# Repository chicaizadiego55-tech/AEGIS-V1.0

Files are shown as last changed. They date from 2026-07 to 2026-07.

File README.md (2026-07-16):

<p align="center">
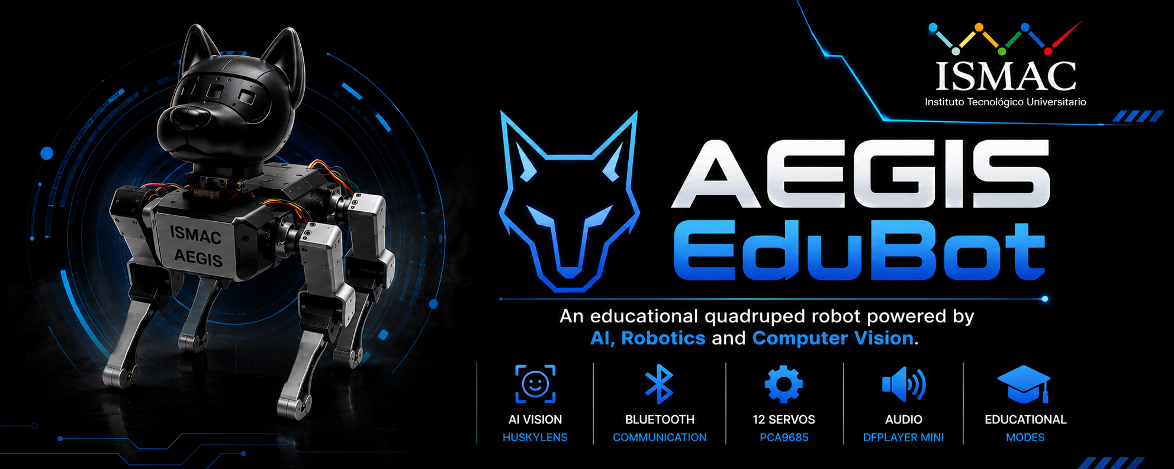
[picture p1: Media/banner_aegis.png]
AEGIS EduBot Banner
  
</p>

<h1 align="center">🐺 AEGIS EduBot</h1>

<p align="center">
An educational quadruped robot powered by ESP32, computer vision, and artificial intelligence.
</p>

<p align="center">






</p>

---

# 📖 Overview

AEGIS (Automated Educational Guide with Intelligent System) is an educational quadruped robot designed to bring artificial intelligence and robotics closer to students through interactive learning experiences.

Its modular architecture combines computer vision, intelligent locomotion, Bluetooth communication and educational activities to promote STEM learning and environmental awareness.

---

# ✨ Features

- 🤖 Quadruped robot
- 👁️ HuskyLens AI Vision
- 📱 Bluetooth communication
- 🎵 DFPlayer Mini audio
- ⚙️ 12 Servo Motors
- 🔋 Battery powered
- 🖨️ Fully 3D Printed
- 🌱 Environmental education

---

# 🎯 Educational Modes

## 👤 Face Recognition

Recognizes previously learned faces and interacts with the user.

---

## 🎨 English Color Learning

Identifies colors while teaching their pronunciation in English.

---

## ♻️ Waste Classification

Recognizes recyclable materials to promote environmental awareness.

---

# 🛠 Hardware

| Component | Model |
|---|---|
| Microcontroller | ESP32 DevKitC V4 |
| Vision | HuskyLens 2 |
| PWM Driver | PCA9685 |
| Audio | DFPlayer Mini |
| Servos | 12x Servo Motors |
| Batteries | Li-Ion 18650 |
| Structure | PLA+ / PETG |

---

# 🚀 Getting Started

Clone the repository

```bash
git clone https://github.com/chicaizadiego55-tech/AEGIS-V1.0.git
```

Open the firmware

```text
Firmware/AEGIS.ino
```

Compile using Arduino IDE with ESP32 Boards installed.

---
# 📄 Documentation

| Folder | Description |
|---|---|
| BOM | Bill of Materials |
| CAD | 3D Models |
| Docs | User & Technical Manuals |
| Electronics | Schematics |
| Firmware | Source Code |
| Results | Validation Data |

---

# 👨‍💻 Developed by

ISMAC – Instituto Tecnológico Universitario

AEGIS EduBot © 2026

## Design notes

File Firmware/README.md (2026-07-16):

# AEGIS EduBot - Firmware 

Este firmware está modularizado para la fácil compilación y control del robot móvil cuadrúpedo AEGIS.

## Requisitos de Librerías
Asegúrate de instalar las siguientes dependencias en tu Arduino IDE o PlatformIO:
1. **Adafruit PWM Servo Driver Library** (para el chip PCA9685)
2. **DFRobot_Huskylens** (para la cámara inteligente)
3. **DFRobotDFPlayerMini** (para el reproductor de sonido)

## Cómo compilar
1. Crea una carpeta llamada `AEGIS` en tu directorio de proyectos de Arduino.
2. Clona o copia el contenido de `AEGIS.ino` dentro de esa carpeta.
3. Crea un subdirectorio llamado `src` al mismo nivel de tu archivo `.ino`.
4. Añade todos los archivos `.h` y `.cpp` dentro de la carpeta `src/`.
5. Abre `AEGIS.ino` en el Arduino IDE y presiona **Upload** (Subir) seleccionando la placa **ESP32 Dev Module**.

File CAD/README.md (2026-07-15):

# Modelos CAD - AEGIS

Esta carpeta contiene los archivos CAD del perro robot **AEGIS**.

## Contenido

-   Diseno_Final.SLDPRT: Modelo CAD principal.
-   SolidWorks: Piezas 

## Software

-   SolidWorks.

## Nota

-   Modelo mecánico del robot.

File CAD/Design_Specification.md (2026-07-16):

# Especificación del diseño mecánico

-   Proyecto: AEGIS
-   Material recomendado: PLA+ o PETG
-   Tecnología: Impresión 3D FDM
-   Componentes integrados: ESP32, HuskyLens 2, PCA9685, DFPlayer Mini y 12 servomotores.

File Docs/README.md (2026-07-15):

# Documentación

Esta carpeta contiene la documentación oficial del proyecto **AEGIS**.

## Contenido

– Guía para la operación del robot.
– Información técnica del hardware y software.
– Presentación general del proyecto.

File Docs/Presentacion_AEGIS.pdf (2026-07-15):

# AEGIS EduBot

### Asistente Robótico Educativo para la Estimulación del Aprendizaje Inicial y la Conciencia Ambiental

Presentación de Defensa de Proyecto de Innovación • 2026

# El Problema

Desafío en Educación Inicial: Los métodos tradicionales de enseñanza para niños de 3 a 5 años sufren de falta de interactividad dinámica, dificultando la retención y la motivación temprana en áreas clave como el bilingüismo y la ecología.

Falta de herramientas tecnológicas interactivas inclusivas adaptadas a la primera infancia.

Dificultad para internalizar hábitos sostenibles (separación de residuos) desde edades tempranas.

Baja exposición práctica a idiomas extranjeros (Inglés) en entornos vulnerables o tradicionales.

•

•

•

AEGIS EduBot — Defensa Final

# Objetivos del Proyecto

Objetivo General

Desarrollar una herramienta tecnológica integral capaz de estimular el aprendizaje en educación inicial mediante visión artificial e interacción humano-robot, convirtiendo la tecnología en una experiencia cercana y dinámica para niños de 3 a 5 años.

Objetivos Específicos

Diseñar e implementar una plataforma móvil cuadrúpeda robusta y visualmente amigable para entornos infantiles.

Integrar algoritmos de inteligencia artificial embebida para reconocimiento facial, clasificación de colores y separación de residuos.

Validar la efectividad pedagógica del robot mitigando errores técnicos (como variaciones de luz ambiental).

•

•

•

AEGIS EduBot — Defensa Final

# ¿Qué es AEGIS?

AEGIS es un ecosistema robótico integral que une Hardware Avanzado, Inteligencia Artificial e Identidad Visual Empática.

Plataforma Cuadrúpeda: Posee 12 grados de libertad independientes que replican los movimientos orgánicos de una mascota viva.

Estética Humana-Robot: Su apariencia de perro amigable disminuye la brecha de desconfianza infantil y estimula el aprendizaje afectivo.

Inteligencia Embebida: No requiere conexión constante a la nube; procesa localmente visión artificial y voz.

•

•

•

AEGIS EduBot — Defensa Final

# Diseño Mecánico y Electrónico

Cinemática: Estructura robusta optimizada con 12 actuadores servo TowerPro MG995 con piñonería metálica.

Arquitectura Electrónica: Centrada en el microcontrolador de doble núcleo ESP32, asistido por un controlador PWM independiente PCA9685 vía bus I2C.

Alimentación Eficiente: Segmentación de líneas lógica y potencia (6V regulados por convertidor Buck) para mitigar ruidos electromagnéticos y caídas de tensión (brownouts).

•

•

•

AEGIS EduBot — Defensa Final

# Visión Computacional y Bluetooth

Solución a Variaciones de Luz: En lugar de usar detección cromática nativa, se implementó el algoritmo de Clasificación de Objetos mediante redes neuronales convolucionales en el sensor HuskyLens, logrando un 98.4% de precisión en el aula.

HuskyLens IA: Coprocesador de visión artificial autónomo de respuesta rápida.

Comunicación Inalámbrica: Enlace Bluetooth integrado en el ESP32 para comando remoto de marchas, telemetría y configuración ágil desde una App móvil dedicada.

•

•

AEGIS EduBot — Defensa Final

# Modos de Funcionamiento

Modo | Tecnología Implicada | Impacto Pedagógico
1. Reconocimiento Facial | Deep Learning Facial (HuskyLens) | Genera un vínculo afectivo inicial y bienvenida personalizada mediante audio interactivo.
2. Colores en Inglés | Clasificación de Tarjetas Didácticas | Fortalece el bilingüismo temprano asociando la estimulación visual con la fonética correcta.
3. Clasificación de Residuos | Reconocimiento de Patrones Ecológicos | Desarrolla la conciencia ambiental práctica guiando al niño sobre el contenedor adecuado.

AEGIS EduBot — Defensa Final

# Resultados y Contribución ODS

Validación Técnica Exitosa: Estabilidad cinemática robusta y control síncrono multitarea implementado sobre FreeRTOS.

ODS 4 (Educación de Calidad): Metodologías innovadoras y lúdicas al alcance de la infancia temprana.

ODS 10 (Reducción de Desigualdades):** Democratización de herramientas robóticas e introducción lingüística.

ODS 12 y 13 (Consumo Responsable / Acción Climática):** Hábitos ecológicos prácticos y sostenibles arraigados desde la niñez.

•

•

•

•

AEGIS EduBot — Defensa Final

# Conclusiones y Trabajo Futuro

«La tecnología no adquiere valor por los componentes que lleva dentro, sino por la realidad que es capaz de transformar afuera».

Conclusión: La inteligencia artificial y la robótica móvil ya no pertenecen en exclusiva a laboratorios avanzados; son viables y efectivas hoy dentro del aula infantil.

Mejoras Futuras: Implementación analítica de Cinemática Inversa (IK) asistida por sensor IMU MPU6050 y actualizaciones inalámbricas Firmware OTA.

•

•

AEGIS EduBot — Defensa Final

# ¡Muchas Gracias!

¿Preguntas o Comentarios del Jurado?

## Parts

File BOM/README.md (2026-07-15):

# Bill of Materials (BOM)

Esta carpeta contiene la lista de todos los materiales y componentes utilizados en el desarrollo de **AEGIS**, un perro robot basado en ESP32.

## Contenido

- **BOM_AEGIS.xlsx**: Lista completa de materiales, componentes electrónicos, elementos mecánicos y consumibles utilizados en el proyecto.

## Información incluida

Cada componente incluye:

- Nombre del componente
- Cantidad
- Especificación
- Función o descripción

## Materiales considerados

- Electrónica
- Actuadores
- Sensores
- Alimentación
- Materiales de impresión 3D
- Tornillería y elementos de ensamblaje
- Consumibles de fabricación

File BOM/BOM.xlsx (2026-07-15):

Componente | Cantidad | Especificación | Función/Observaciones
ESP32-DevKitc V4 | 1 | ESP32-WROOM-32 | Control principal
PCA 9685 | 1 | Driver PWM 16 canales | Control de servomotores
HUSKYLENS 2 | 1 | DFRobot | Visión artificial
DF Player Mini | 1 | Módulo MP3 | Reproducción de audio
Parlante | 1 | 3W 4Ω | Salida de audio
MicroSD | 1 | Clase 10 | Almacenamiento de audios
Condesador | 2 | 10 µF | Filtrado
Servomotor | 12 | MG995R | Movimiento
BATERIA RECARGABLE pila litio | 1 | 18650 8800mAh 11.1V | Alimentación principal
BATERIA RECARGABLE pila litio | 1 | 18650 5600mAh 7.4V | Alimentación auxiliar
Reguladores de voltaje | 1 | 15A 5V | Servos
Reguladores de voltaje | 1 | 7A 5V | Electrónica
Interruptores | 2 | ON/OFF | Encendido
Estaño Soldadura En Rollo | 1 | 1.0 mm 100g 60/40 | Soldadura
Pasta para Soldar King'sdun | 1 | 10 g | Soldadura
Tubo aislante termofundente | 3 | Metros | Aislamiento
Amarras Plásticas | 1 | 3.6x150 mm (100 u) | Organización de cables
Filamento PLA+ 0 PETG | 1 | 1.5 kg | Impresión 3D
Tornillería variada | 1 | M2/M3 | Ensamble
Conectores JST | 4 | 2 pines | Alimentación
Cables Jumper Macho-Macho (M-M) | 1 | 20 unidades | Conexiones
Cables Jumper Macho-Hembra (H-M) | 1 | 20 unidades | Conexiones
Cables Jumper Hembra-Hembra (H-H) | 1 | 20 unidades | Conexiones

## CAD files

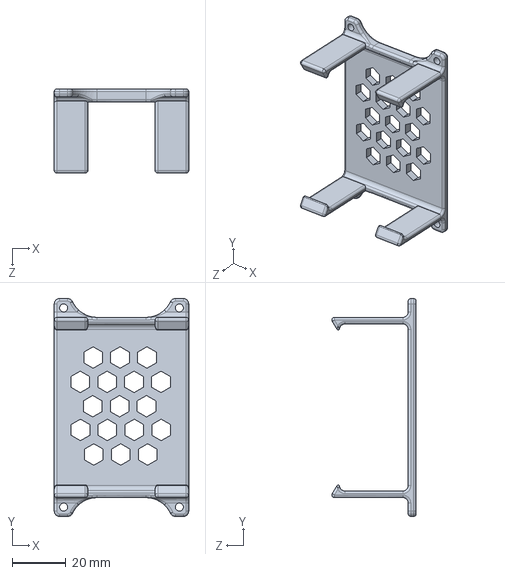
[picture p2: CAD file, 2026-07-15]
CAD/diseñoFinal/diseño_Final.SLDPRT
50.0 x 81.0 x 31.4 mm

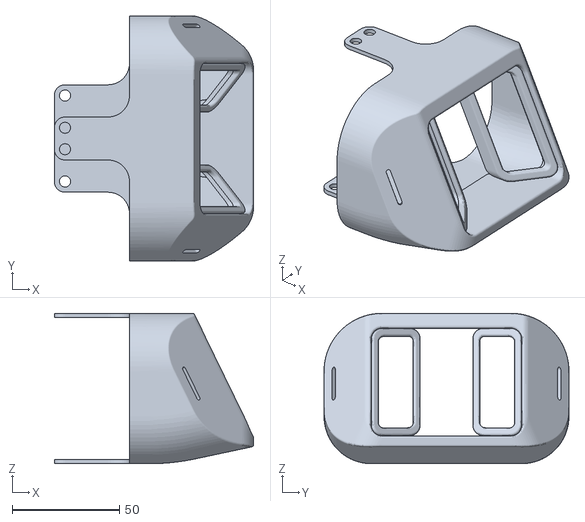
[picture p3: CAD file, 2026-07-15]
CAD/SolidWorks/Cabeza perro.stl
92.8 x 114.0 x 70.0

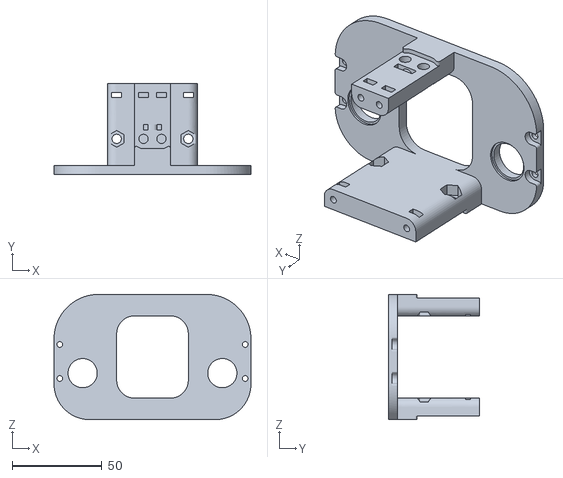
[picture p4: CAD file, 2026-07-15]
CAD/SolidWorks/Coxis frontal.stl
110.0 x 51.0 x 70.0

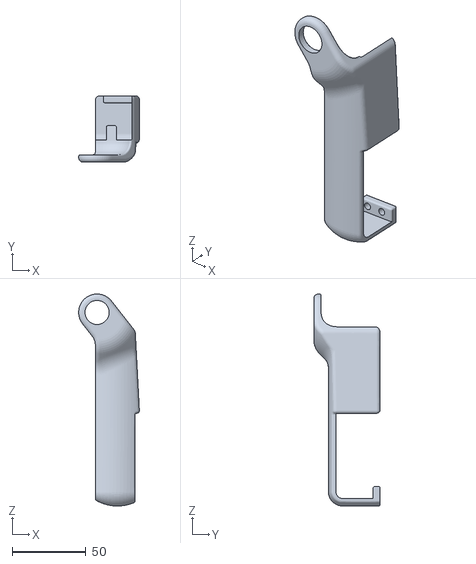
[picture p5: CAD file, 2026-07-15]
CAD/SolidWorks/Femur izquierdo 2.stl
41.2 x 45.0 x 143.5

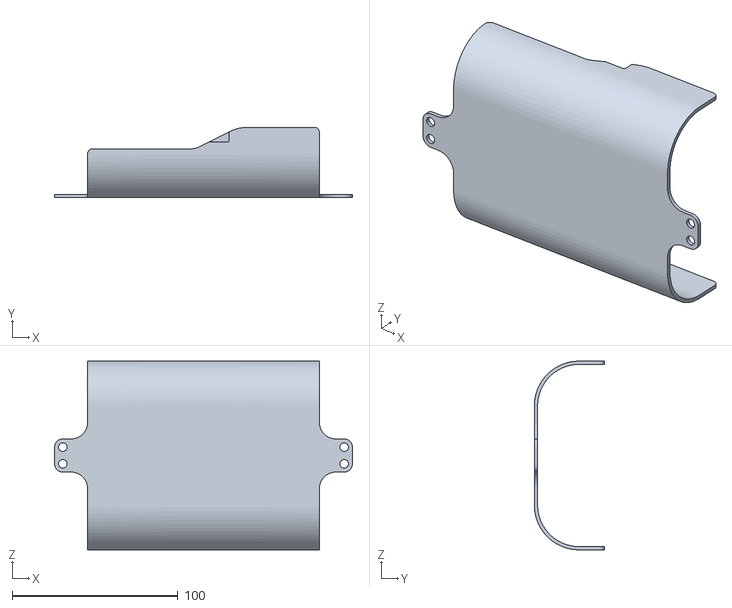
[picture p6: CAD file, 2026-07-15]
CAD/SolidWorks/Base cuerpo.stl
180.0 x 42.5 x 114.0

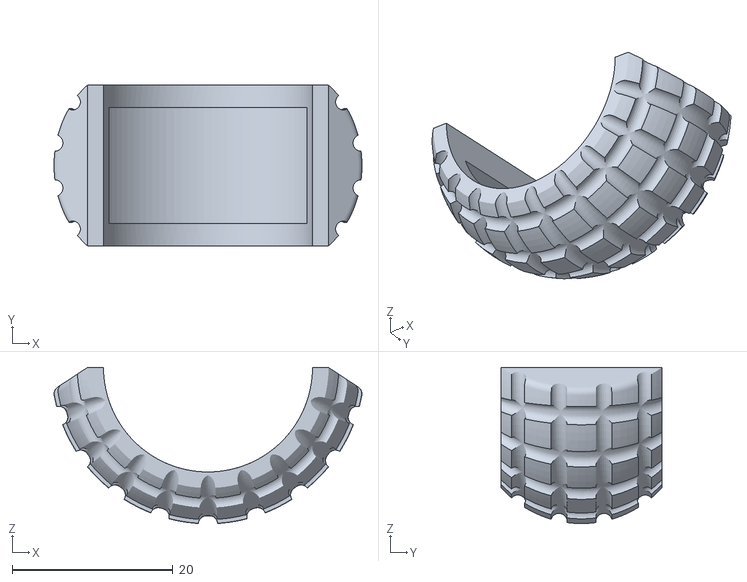
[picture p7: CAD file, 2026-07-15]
CAD/SolidWorks/Pie.stl
38.3 x 20.0 x 19.4

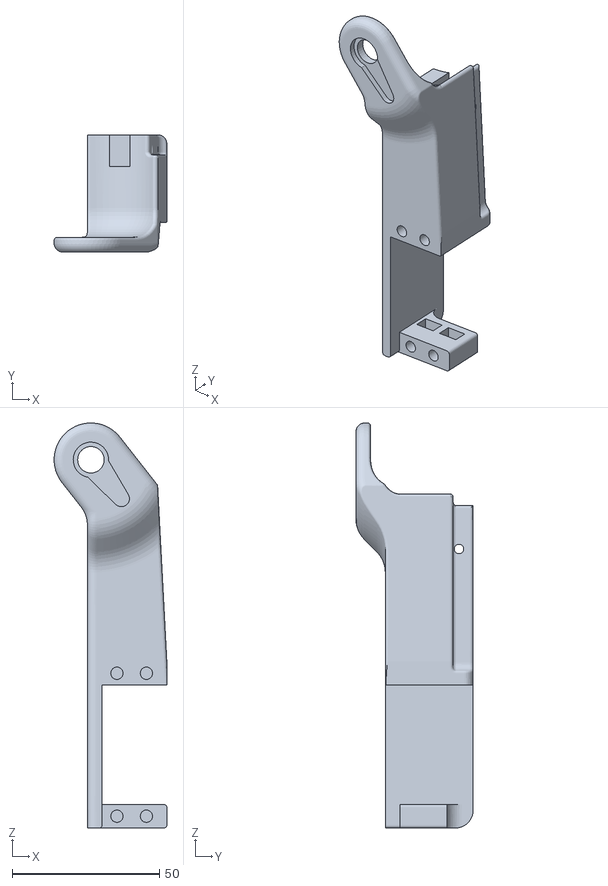
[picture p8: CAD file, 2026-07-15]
CAD/SolidWorks/Femur izquierdo 1.stl
38.2 x 39.8 x 137.4

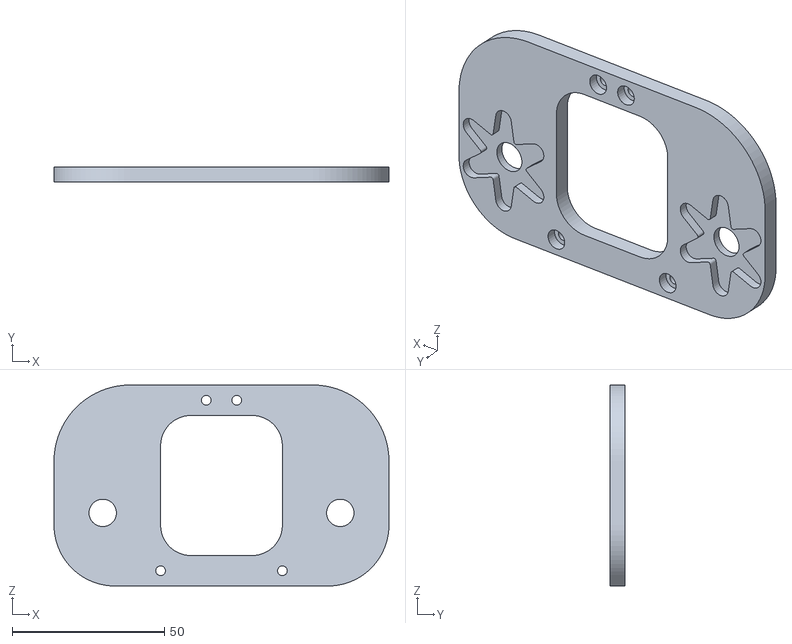
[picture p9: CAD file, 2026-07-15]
CAD/SolidWorks/Soporte Coxis.stl
110.0 x 5.00 x 66.0

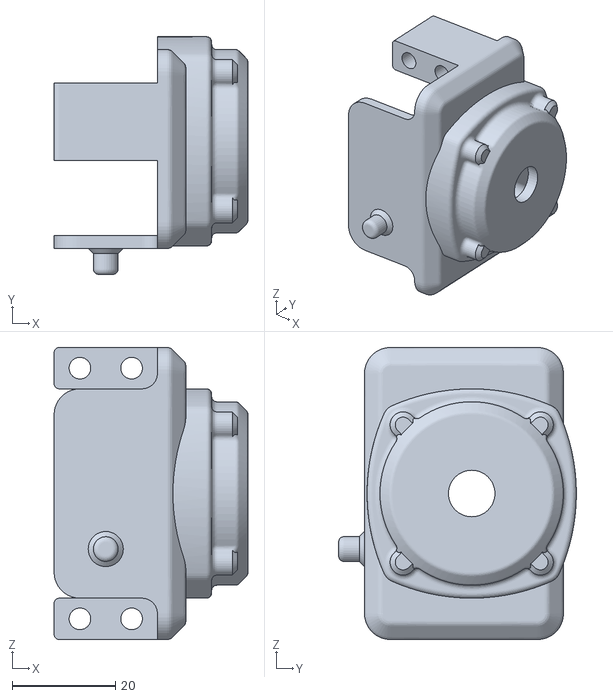
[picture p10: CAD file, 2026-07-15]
CAD/SolidWorks/Soporte coxis D.stl
37.5 x 46.0 x 56.5

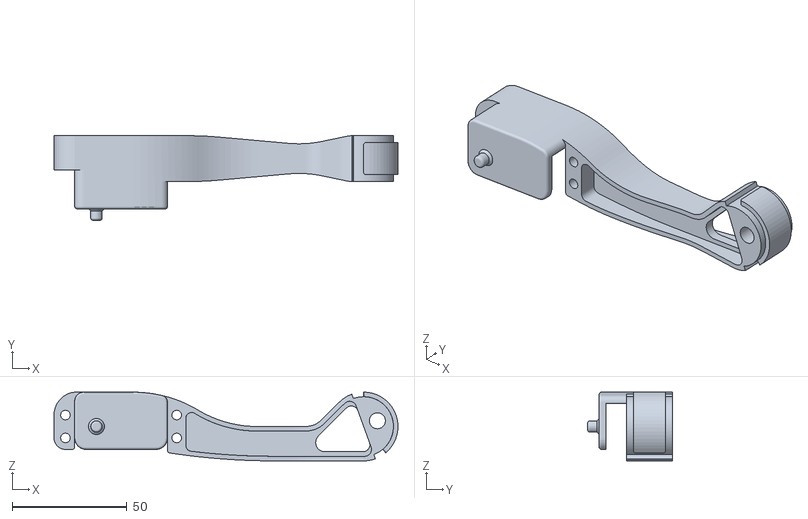
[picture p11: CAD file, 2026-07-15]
CAD/SolidWorks/Tibia Derecha.stl
150.0 x 36.9 x 30.0

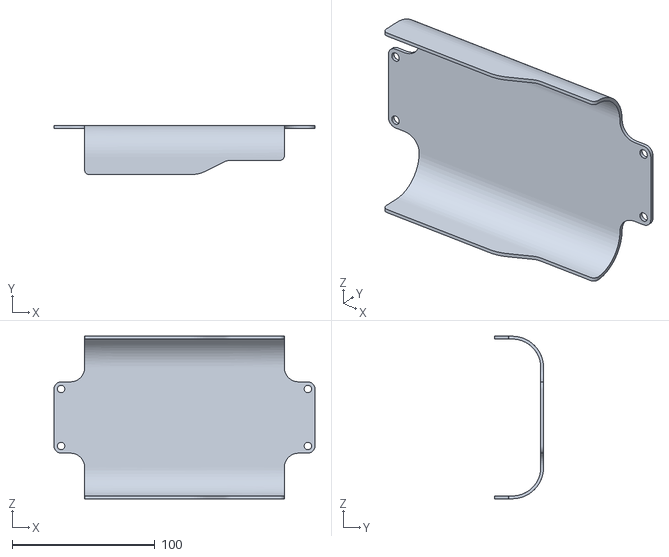
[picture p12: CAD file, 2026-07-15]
CAD/SolidWorks/Tapa superior.stl
183.0 x 34.5 x 114.0

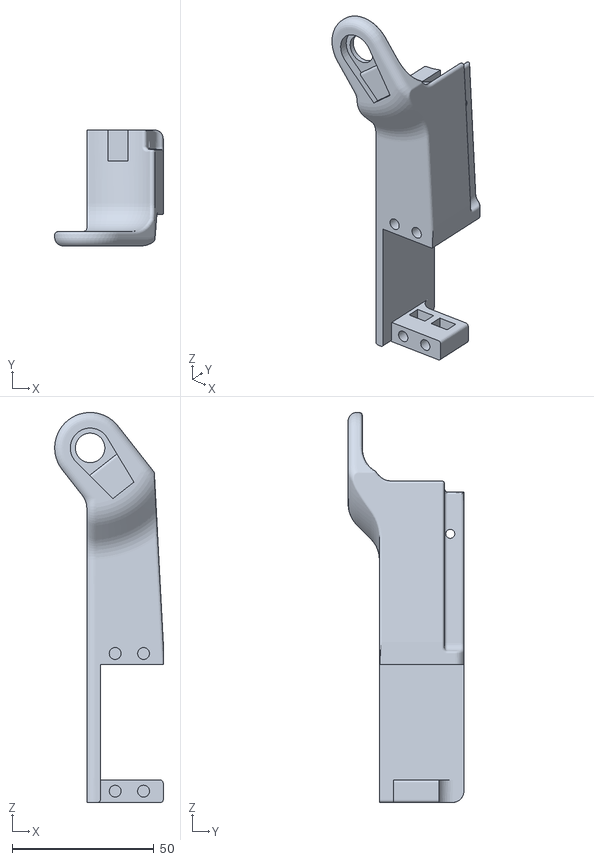
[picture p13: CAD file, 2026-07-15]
CAD/SolidWorks/Femur derecho 1.stl
38.2 x 40.8 x 137.4

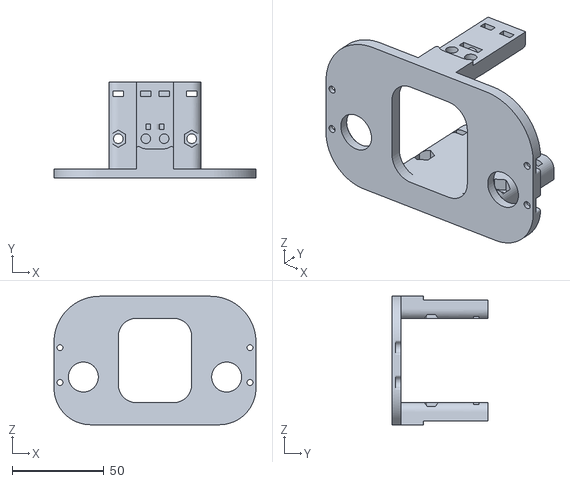
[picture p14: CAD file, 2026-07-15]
CAD/SolidWorks/Coxis trasero.stl
110.0 x 52.5 x 70.0

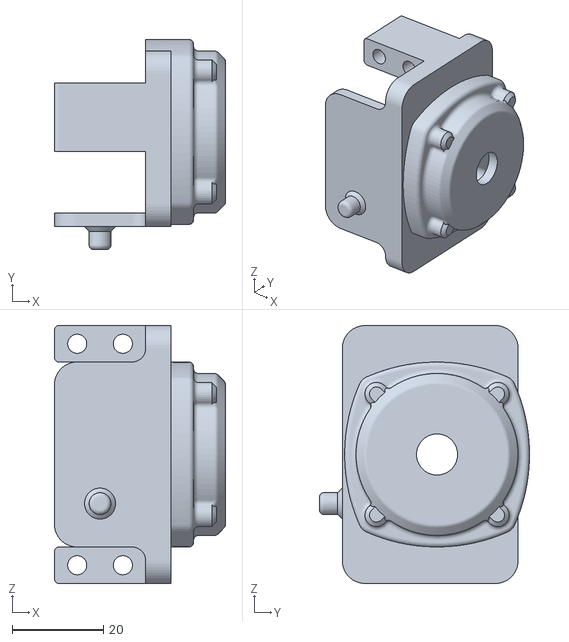
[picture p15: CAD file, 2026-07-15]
CAD/SolidWorks/Soporte coxis I.stl
37.5 x 46.0 x 56.5

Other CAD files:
CAD/SolidWorks/Femur derecho 2.stl
CAD/SolidWorks/Tibia Izquierda.stl

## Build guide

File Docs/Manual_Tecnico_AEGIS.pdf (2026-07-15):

# AEGIS EduBot

# Manual Técnico de Arquitectura, Electrónica y Firmware

## Documentación Completa para Desarrolladores e Ingenieros

Proyecto: Asistente Robótico Cuadrúpedo Educativo

Versión del Firmware: v2.1.0-stable

Fecha: Julio, 2026

Autoría: Equipo de Desarrollo e Innovación Tecnológica AEGIS

AEGIS EduBot - Manual Técnico | Página 1 de 5

# 1. Arquitectura General del Sistema

El sistema AEGIS EduBot está estructurado bajo una arquitectura jerárquica de procesamiento y control de lazo abierto para la ejecución cinemática, asistido por un lazo cerrado de visión artificial en tiempo real. La arquitectura separa los flujos de tareas de alta prioridad (visión computacional y procesamiento de lenguaje/ audio) de las tareas de control mecánico síncrono (generación de señales de modulación por ancho de pulsos o PWM para los actuadores).

El núcleo de procesamiento central está constituido por el microcontrolador ESP32, el cual administra tres interfaces de comunicación periférica concurrentes:

I2C Bus (Inter-Integrated Circuit): Canal de control dedicado a la comunicación con el driver multicanal PCA9685 a una frecuencia de reloj estándar de 400 kHz.
UART Bus (Universal Asynchronous Receiver-Transmitter): Dos puertos dedicados independientes; uno mapeado al coprocesador de visión inteligente HuskyLens (9600-115200 bps) y otro al módulo decodificador de audio MP3 DFPlayer Mini (9600 bps).
Bluetooth Serial Link: Canal inalámbrico integrado para la telemetría de estados y la recepción remota de comandos de marcha (gaits).

# 2. Diseño Mecánico

El chasis y las extremidades de AEGIS EduBot han sido diseñados bajo criterios de optimización estructural, minimización de masa inercial y estabilidad del centro de gravedad. La configuración mecánica consiste en un robot móvil cuadrúpedo con 12 grados de libertad (12 DoF) independientes, lo que equivale a tres articulaciones activas por extremidad:

Articulación Coxa (Cadera - Rotación Horizontal): Permite la abducción y aducción de la extremidad.
Articulación Femur (Cadera - Rotación Vertical): Gobierna la elevación primaria del eslabón proximal.
Articulación Tibia (Rodilla - Rotación Vertical): Controla la extensión y flexión del eslabón distal.

Todos los eslabones estructurales se encuentran fabricados en polímero acrilonitrilo butadieno estireno (ABS) y poliácido láctico (PLA) de alta densidad mediante manufactura aditiva y corte asistido por computadora. Las uniones de transmisión de torque mecánico acoplan de manera directa el eje estriado de los servomotores al chasis, utilizando brazos de control de aluminio (horns) para evitar deflexiones por fatiga elástica.

# 3. Diseño Electrónico y Lista de Materiales (BOM)

El circuito electrónico está diseñado para mitigar el ruido electromagnético inducido por los transitorios de corriente de los motores y evitar caídas de voltaje de retroalimentación hacia los sensores lógicos.

•

•

•

1.

2.

3.

## 3.1. Lista de Materiales Completa (BOM)

Componente | Fabricante/Modelo | Descripción Técnica | Cantidad | Interfaz de Control
Microcontrolador | Espressif ESP32 WROOM-32E | Dual-Core 32-bit MCU, 240MHz, Wi-Fi & BT | 1 | Núcleo Central
Controlador PWM | Adafruit / PCA9685 | 16-Channel 12-bit PWM Driver I2C | 1 | I2C (Dirección 0x40)
Servomotores | TowerPro MG995 | Metal Gear High Torque Servo, 13kg/cm a 6V | 12 | PWM individual desde PCA9685
Cámara IA | DFRobot HuskyLens V2 | AI Vision Sensor, K210 Core, Pantalla LCD 2" | 1 | UART (Rx/Tx)
Módulo de Audio | DFRobot DFPlayer Mini | Hardware MP3 Decoder, Ranura MicroSD | 1 | UART Software / Hardware Serial
Regulador DC-DC | XL4016 / Buck Converter | Step-down Converter, Capacidad máx. 8A | 1 | Alimentación de Potencia

## 3.2. Módulos y Análisis de Alimentación

El sistema de energía se segmenta estrictamente en dos líneas mediante un nodo común de referencia (GND compartida):

Línea de Potencia (6.0V): Suministrada por el convertidor reductor (Buck) XL4016, capaz de drenar picos de hasta 8A. Alimenta directamente las pistas de los 12 servomotores MG995. La ecuación de potencia requerida en el peor escenario de bloqueo síncrono de 4 patas es: P_{max} = I_{stall} imes V imes N = 1.2A imes 6V imes 4 = 28.8W.
Línea Lógica (5.0V / 3.3V): Regulada de forma independiente para aislar al ESP32 y a la HuskyLens de las caídas de tensión (brownouts) provocadas por los arranques mecánicos.

## 3.3. Diagrama Eléctrico Teórico de Conexiones

•

•

### [Batería LiPo 7.4V] ───► [Regulador Buck XL4016] ───► VCC Potencia (6V) ───► [PCA9685 V+ Servos]

│
└──────► [Regulador Lógico LDO] | ───► VCC Lógica (5V) | ───► [ESP32

### VIN / HuskyLens VCC]

### [ESP32] GPIO 21 (SDA) ◄────────────────► [PCA9685 SDA] [ESP32] GPIO 22 (SCL) ◄────────────────► [PCA9685 SCL] [ESP32] GPIO 16 (RX2) ◄───────────────── [HuskyLens TX] [ESP32] GPIO 17 (TX2) ─────────────────► [HuskyLens RX] [ESP32] GPIO 25 (TX1) ─────────────────► [DFPlayer RX con R=1kΩ]

# 4. Firmware y Estructura del Código

El código fuente está modularizado en paradigma orientado a objetos e interrupciones temporizadas distribuidas en tareas de FreeRTOS para el ESP32, garantizando el determinismo en el procesamiento.

## 4.1. Librerías Utilizadas

Wire.h: Control nativo del bus maestro I2C.
Adafruit_PWMServoDriver.h: Abstracción de registros del circuito PCA9685. HUSKYLENS.h: Decodificación y empaquetamiento del protocolo binario de la HuskyLens. DFRobotDFPlayerMini.h: Interfaz de control del reproductor de sonido sobre el bus serial. BluetoothSerial.h: Implementación del perfil SPP (Serial Port Profile) clásico.

## 4.2. Estructura de Módulos Core

# 5. Procesos Especializados: Entrenamiento y Calibración

## 5.1. Proceso de Entrenamiento de la HuskyLens

Para mitigar la inestabilidad lumínica descrita en el diseño pedagógico para el reconocimiento de colores, se inhabilitó el modo nativo de colorimetría RGB y se configuró el algoritmo de Clasificación de Objetos (Object Classification) basado en redes neuronales convolucionales embebidas:

Seleccionar el modo Object Classification mediante el dial superior de la cámara.
Presentar la tarjeta didáctica del color (ej. Rojo) cubriendo el 60% del encuadre bajo condiciones de iluminación estándar (300-500 lux).

•
•
•
•
•

### AEGIS_Firmware/

│

├── AEGIS_Firmware.ino # Inicialización general, Setup y Loop principal de FreeRTOS ├── Kinematics.h / .cpp # Lógica matemática de gaits (marchas), trayectorias e interpolación ├── VisionManager.h / .cpp # Máquina de estados para control de la HuskyLens y modos de IA ├── AudioManager.h / .cpp # Abstracción de pistas de audio y eventos sonoros de respuesta

└── Config.h | # Definición de pines, calibración de offsets y constantes

### físicas

1.
2.

Mantener presionado el botón de aprendizaje (Learning Button) mientras se rota ligeramente la tarjeta para capturar múltiples ángulos y variaciones. La HuskyLens extraerá los mapas de características y asignará el ID 1.
Repetir el proceso para tarjetas subsiguientes (Azul -> ID 2, Verde -> ID 3). Los pesos lógicos se

guardan en la memoria Flash no volátil de la cámara.

## 5.2. Calibración Analítica de Servomotores

Debido a las variaciones mecánicas en el acoplamiento físico de los brazos de los servomotores, cada actuador requiere una corrección por software (Offset) para garantizar que la señal PWM corresponda exactamente a los ángulos geométricos reales de la cinemática. La función de mapeo se rige por la ecuación:

PWM_{pulse} = PWM_{offset} + \left( rac{ heta_{deg}}{180} imes (PWM_{max} - PWM_{min}) ight)

El desarrollador debe ajustar los valores de la matriz servoOffsets[12] en el archivo Config.h utilizando

un goniómetro físico hasta que todas las extremidades formen un ángulo ortogonal perfecto de 90° en modo de reposo.

NOTA DE SEGURIDAD PARA DESARROLLADORES: No energizar el sistema de potencia (6V) si los servomotores se encuentran mecánicamente trabados o bloqueados por el chasis. La corriente de stall prolongada degradará de forma irreversible las escobillas internas del motor MG995.

# 6. Mantenimiento y Mejoras Futuras

## 6.1. Plan de Mantenimiento Preventivo

Verificación de Pernos: Reajustar la tornillería de acero inoxidable M3 en las articulaciones cada 15 horas de operación para compensar el juego por vibraciones armónicas.
Lubricación de Engranajes: Aplicar grasa de litio blanca de baja densidad en el tren de engranajes metálicos de los servomotores en caso de detectar ruidos de fricción seca.

## 6.2. Posibles Mejoras Futuras

Cinemática Inversa (IK): Migración de las marchas empíricas actuales hacia un motor analítico de ecuaciones trigonométricas en tiempo real para adaptabilidad del terreno empleando un sensor IMU MPU6050.
Actualización OTA (Over-The-Air): Implementar actualización inalámbrica del firmware mediante servidor web local embebido en el ESP32 para agilizar el mantenimiento en las escuelas.

3.

4.

•

•

•

•

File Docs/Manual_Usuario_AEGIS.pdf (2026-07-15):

PROYECTO DE INNOVACIÓN TECNOLÓGICA

# AEGIS EduBot

## Manual de Usuario y Guía de Funcionamiento

Asistente Robótico Educativo para la Estimulación del Aprendizaje Inicial y la Conciencia Ambiental

Desarrollado para niños de 3 a 5 años, integrando Visión Artificial, Inteligencia Artificial e Interacción Humano-Robot en una plataforma cuadrúpeda amigable.

Versión: 1.0 | Año: 2026
Diseño y Desarrollo: Equipo de Robótica Educativa | Público Objetivo: Educadores e Infancia

# 1. Introducción a AEGIS

Hoy en día un robot puede procesar, identificar y clasificar un objeto en una fracción de segundo, mucho antes de que un ser humano decida qué hacer con él [cite: 87]. Sin embargo, la verdadera pregunta ya no es qué tan inteligente puede llegar a ser un robot, sino qué tan capaz puede ser de despertar la curiosidad, enseñar y transformar la forma en la que aprende un niño [cite: 88].

AEGIS EduBot es un asistente robótico educativo desarrollado para demostrar que la inteligencia artificial, la robótica y la visión artificial pueden convertirse en herramientas capaces de fortalecer el aprendizaje desde la primera infancia y fomentar la conciencia ambiental mediante experiencias lúdicas e interactivas [cite: 90]. Su diseño responde a la necesidad de crear un recurso educativo inclusivo, dinámico y cercano que motive a los niños de 3 a 5 años a explorar conocimientos fundamentales [cite: 94].

## ¿Por qué un Robot Cuadrúpedo?

A diferencia de un brazo robótico fijo que limita la interacción al espacio de trabajo, o de un robot con ruedas que restringe su desplazamiento a superficies sumamente planas, la plataforma cuadrúpeda de AEGIS integra diseño mecánico, electrónica de vanguardia, programación avanzada e inteligencia artificial en un solo dispositivo [cite: 97, 98]. Esta estructura física genera un desplazamiento natural y orgánico, asemejándose a una mascota real y estimulando un vínculo afectivo y de confianza necesario para facilitar el proceso de aprendizaje [cite: 98, 100].

Identidad Visual Amigable: El rostro de AEGIS ha sido rediseñado a partir de los primeros prototipos técnicos para emular a un perro amigable [cite: 99, 100]. Comprendiendo que para un niño la confianza forma parte primordial de la aprehensión del conocimiento, esta nueva estética invita a una interacción natural y reduce la distancia entre el infante y la tecnología [cite: 100].

«La tecnología no adquiere valor por los componentes que lleva dentro, sino por la realidad que es capaz de transformar afuera» [cite: 125].

# 2. Características Principales del Robot

AEGIS se compone de un ecosistema tecnológico integrado con hardware especializado de procesamiento y control [cite: 101, 103]. A continuación se detallan las especificaciones y la anatomía física del asistente:

Componente | Función Principal | Especificación Técnica
Microcontrolador Principal | Cerebro del sistema, controla movimiento, audio, bluetooth y lógica de visión [cite: 103]. | ESP32 de alta velocidad [cite: 103].
Controlador de Servos | Genera señales PWM para la sincronización precisa de las extremidades [cite: 104]. | Módulo PCA9685 [cite: 104].
Actuadores (Articulaciones) | Permiten 12 grados de libertad independientes para caminar y balancearse [cite: 102]. | 12 Servomotores MG995 [cite: 102].

Manual de Usuario — AEGIS EduBot

Tecnología Educativa, Robótica e Inclusiva | Página 2 de 7

Sensor de Visión Artificial | Cámara inteligente con modelos integrados de Deep Learning [cite: 106]. | DFRobot HuskyLens [cite: 106].
Alimentación | Suministro eléctrico regulado para garantizar estabilidad mecánica [cite: 104]. | Baterías de Litio a 6 Voltios [cite: 104].

# 3. Componentes Visibles

Al examinar a AEGIS EduBot, se pueden identificar los siguientes elementos clave ubicados estratégicamente:

1. Cabeza / Rostro Amigable: Aloja el sensor de visión artificial y la pantalla LCD del sensor, simulando los ojos y la expresión facial del perrito [cite: 100, 106].
2. Sensor HuskyLens (Ojos): Ubicado en la parte frontal de la cabeza para el reconocimiento en tiempo real [cite: 106].
3. Extremidades Cuadrúpedas (Patas): Cuatro patas independientes, cada una equipada con tres articulaciones y tres servomotores MG995 para brindar el movimiento coordinado (12 Grados de Libertad) [cite: 102].
4. Compartimento de Control Interno (Cuerpo): Protege el microcontrolador ESP32, el módulo de servos PCA9685, la placa de distribución eléctrica y el sistema de audio [cite: 103, 104].
5. Compartimento de Batería: Localizado en la parte inferior para mantener un centro de gravedad bajo y estable [cite: 104].

# 4. Encendido, Apagado y Carga de la Batería

## Instrucciones de Encendido y Apagado

Para iniciar el robot, asegúrese de que esté colocado en una superficie plana y despejada para permitir la calibración automática de las articulaciones en su posición de pie estándar [cite: 102].

Paso 1: Localice el interruptor principal de energía situado en la parte trasera del chasis.
Paso 2: Desplace el interruptor a la posición ON. Notará que los LED del ESP32 y de la HuskyLens se encienden, y los 12 servomotores se alinearán en una postura estable de inicio [cite: 102, 103, 106].
Paso 3: Para apagar el robot, simplemente desplace el interruptor a la posición OFF. Evite mover de manera forzada las extremidades mientras el robot esté encendido para prevenir daños en los engranajes metálicos [cite: 102].

## Carga de la Batería

AEGIS se alimenta de un banco de baterías de litio de alta eficiencia regulado a un nivel constante de 6V para garantizar la máxima potencia y estabilidad en los movimientos de los servos MG995 [cite: 104]. Siga estas instrucciones para la recarga de energía:

- Indicador de Batería Baja: Cuando los movimientos del robot pierdan fuerza o se presenten reinicios inesperados, es indicador de que la batería requiere recarga inmediata.
- Proceso de Carga: Apague el robot por completo (interruptor en OFF). Extraiga con cuidado el módulo de baterías y conéctelo al cargador inteligente suministrado de fábrica.
- Medida de Seguridad: Utilice únicamente cargadores y reguladores autorizados para evitar sobrecargas y asegurar un funcionamiento estable y seguro del sistema de potencia [cite: 104].

# 5. Conexión Bluetooth

AEGIS dispone de un módulo Bluetooth integrado en el microcontrolador principal ESP32 [cite: 103], lo que permite una comunicación bidireccional con una aplicación móvil dedicada para el control de gaits (marchas) y la selección de modos [cite: 103].

1. Habilitar Conexión: Al encender a AEGIS, el ESP32 comenzará a emitir la señal inalámbrica automáticamente.
2. Enlace desde la App: Abra la aplicación móvil AEGIS Control, pulse sobre el icono de conexión y seleccione el dispositivo reconocido de la lista.
3. Confirmación: Una vez establecida la conexión, el robot realizará una breve inclinación para notificar que la vinculación ha sido exitosa.

# 6. Modos de Funcionamiento

El asistente AEGIS EduBot cuenta con tres modos interactivos de funcionamiento alimentados por la cámara de visión artificial HuskyLens, los cuales han sido diseñados específicamente para responder a necesidades educativas de estimulación inicial [cite: 108, 116].

## Modo 1: Reconocimiento Facial

Este modo permite iniciar un vínculo de confianza inicial y una interacción personalizada con el niño [cite: 109]. Utiliza la red de Deep Learning incorporada en la HuskyLens para memorizar y detectar rostros humanos en tiempo real [cite: 106].

- Funcionamiento: Al detectar el rostro registrado de un niño, el ESP32 procesa el identificador facial y activa una secuencia de saludo amigable (por ejemplo, agitando una pata o inclinando el cuerpo) junto con un mensaje de audio personalizado [cite: 103, 109].

## Modo 2: Aprendizaje de Colores en Inglés

Orientado a fortalecer el bilingüismo desde la primera infancia de forma lúdica [cite: 113]. Inicialmente, el sistema fue concebido utilizando el reconocimiento nativo de colores de la HuskyLens [cite: 110]; sin embargo, durante las fases de validación se detectó que las variaciones de luz ambiental y la intensidad de los tonos alteraban la precisión [cite: 111].

Para corregir este factor y maximizar la confiabilidad en las aulas, la cámara se entrenó con clasificación de objetos mediante tarjetas didácticas previamente registradas que representan cada color de forma nítida [cite: 112]. • Interacción: Cuando el niño presenta una tarjeta de color frente a los ojos de AEGIS, el robot identifica el patrón, lo asocia y reproduce de inmediato un audio con la pronunciación correcta del color en inglés, creando una experiencia educativa dinámica [cite: 113].

## Modo 3: Clasificación de Residuos (Educación Ambiental)

Enfocado en despertar la conciencia ambiental de los niños desde edades tempranas [cite: 90, 114]. Mediante algoritmos de visión artificial, el robot analiza diferentes elementos de desecho presentados en su rango de visualización [cite: 114].

- Funcionamiento: AEGIS identifica si el desecho es orgánico, plástico, papel u otro residuo pre-entrenado [cite: 107, 114]. Posteriormente, a través de audio interactivo y señales de movimiento coordinadas, determina y señala de forma interactiva cuál es el contenedor adecuado para depositar el residuo, promoviendo de manera práctica la adopción de hábitos ecológicos sostenibles [cite: 114, 120].

# 7. Cuidados y Mantenimiento del Robot

Para garantizar la durabilidad de AEGIS EduBot en entornos educativos altamente interactivos, es indispensable seguir las siguientes pautas de cuidado diario:

- Protección de Articulaciones: Los servomotores MG995 poseen piñonería metálica de alta resistencia [cite: 102], pero no deben ser forzados manualmente de manera brusca mientras estén bloqueados eléctricamente. Esto podría barrer el eje interno del motor.
- Sensor de Visión: El lente de la cámara HuskyLens debe permanecer limpio de huellas dactilares y polvo. Límpielo suavemente con un paño de microfibra seco [cite: 106]. Evite el uso de líquidos abrasivos.
- Almacenamiento Seguro: Almacene el robot en un lugar seco, fresco y libre de humedad directa. Procure guardarlo en una superficie nivelada con las extremidades relajadas (apagado).
- Cuidado de la Batería: No exponga el pack de baterías de litio a temperaturas extremas ni lo deje descargado por periodos prolongados de tiempo, a fin de conservar su ciclo de vida útil.

# 8. Solución de Problemas Frecuentes

Si experimenta alguna dificultad durante la puesta en marcha de AEGIS, por favor consulte la siguiente tabla de soluciones:

Falla Detectada | Causa Probable | Acción Recomendada
El robot no se enciende o los servos vibran excesivamente al iniciar. | Nivel de batería críticamente bajo o voltaje desregulado. | Apague el robot, cargue el pack de litio por completo y verifique que el regulador suministre 6V estables [cite: 104].
El robot no reconoce las tarjetas de colores en el aula. | Variaciones de luz intensa en el entorno alteran la captura de imágenes [cite: 111]. | Evite la luz solar directa. Coloque el robot en un área iluminada de forma homogénea y use las tarjetas didácticas pre-registradas [cite: 112].
Falla la comunicación con la App móvil vía Bluetooth. | El Bluetooth del dispositivo móvil está desactivado o fuera de rango. | Reinicie la aplicación, asegúrese de estar a menos de 5 metros de distancia de AEGIS y conéctese nuevamente [cite: 103].
No se escuchan las pronunciaciones o sonidos del robot. | Conexión del parlante aflojada debido a vibraciones del movimiento. | Verifique que los pines de conexión del módulo de audio acoplado al ESP32 estén firmemente asentados [cite: 103].

# 9. Alineación con los Objetivos de Desarrollo Sostenible (ODS)

Cada función desarrollada en AEGIS responde a una necesidad pedagógica real y no únicamente a un reto técnico, lo que permite a este proyecto contribuir de manera tangible a los siguientes ODS de las Naciones Unidas [cite: 116, 117]:

ODS Incorporado | Mecanismo de Contribución del Proyecto
ODS 4: Educación de Calidad | Permite fortalecer el proceso de enseñanza-aprendizaje desde la infancia temprana mediante metodologías didácticas respaldadas por la inteligencia artificial y la robótica [cite: 118].
ODS 10: Reducción de las Desigualdades | Facilita el acceso equitativo a tecnologías educativas avanzadas a niños que tradicionalmente no tienen contacto con ellas, reduciendo las brechas cognitivas, específicamente en la adquisición de un segundo idioma (inglés) desde la niñez [cite: 119].
ODS 12: Producción y Consumo Responsables | Enseña prácticas correctas de separación de residuos en contenedores mediante visión artificial, asimilando patrones proambientales prácticos desde la infancia [cite: 120].
ODS 13: Acción por el Clima | Reconoce que la educación y concientización ambiental desde la niñez es la base fundamental para edificar una sociedad comprometida con el cuidado ecológico y la mitigación del cambio climático [cite: 121].

## Conclusión

Con AEGIS EduBot hemos demostrado que la robótica móvil, la visión computacional y la inteligencia artificial ya no son herramientas exclusivas de laboratorios de alta gama [cite: 126]. Hoy, estas tecnologías están listas para adaptarse al aula de clase, educar, inspirar y sembrar en las nuevas generaciones la curiosidad por el desarrollo científico y el cuidado del planeta [cite: 127]. Porque la verdadera innovación no se predice... se diseña, se programa y se construye [cite: 128].

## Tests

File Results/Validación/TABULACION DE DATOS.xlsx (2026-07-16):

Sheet: MATRIZ DE RESULTADOS ODS4
ODS 4 – Educación de Calidad
Indicador | Sí | No | Participante | C1 | C2 | C3 | CUMPLE ODS 4
El niño completó correctamente la actividad de reconocimiento de colores. | ☐ | ☐ | Niño 1 | ✔ | ✔ | ✔ | Cumple
Colocó correctamente las tarjetas en el tablero. | ☐ | ☐ | Niño 2 | ✔ | ✔ | ✔ | Cumple
Mostró interés durante toda la actividad. | ☐ | ☐ | Niño 3 | ✔ | ✔ | ✘ | Cumple
 |  |  | Niño 4 | ✔ | ✔ | ✔ | Cumple
Considera que el niño aprueba el indicador si cumple al menos 2 de los 3 criterios. |  |  | Niño 5 | ✔ | ✔ | ✔ | Cumple
 |  |  | Niño 6 | ✔ | ✔ | ✔ | Cumple
 |  |  | Niño 7 | ✔ | ✔ | ✔ | Cumple
 |  |  | Niño 8 | ✔ | ✔ | ✔ | Cumple
TABULACION DE DATOS |  |  | Niño 9 | ✔ | ✔ | ✔ | Cumple
CUMPLE | 19 |  | Niño 10 | ✔ | ✔ | ✔ | Cumple
NO CUMPLE | 1 |  | Niño 11 | ✔ | ✔ | ✔ | Cumple
PORCENTAJE | 95% |  | Niño 12 | ✔ | ✔ | ✔ | Cumple
 |  |  | Niño 13 | ✔ | ✔ | ✔ | Cumple
 |  |  | Niño 14 | ✔ | ✔ | ✔ | Cumple
 |  |  | Niño 15 | ✔ | ✔ | ✔ | Cumple
 |  |  | Niño 16 | ✔ | ✔ | ✔ | Cumple
 |  |  | Niño 17 | ✔ | ✔ | ✘ | Cumple
 |  |  | Niño 18 | ✔ | ✔ | ✔ | Cumple
 |  |  | Niño 19 | ✔ | ✔ | ✔ | Cumple
 |  |  | Niño 20 | ✔ | ✘ | ✘ | No cumple

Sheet: MATRIZ DE RESULTADOS ODS10
ODS 10 – Reducción de las Desigualdades
Indicador | Sí | No | Participante | C1 | C2 | C3 | C4 | CUMPLE ODS 10
El niño pudo utilizar el robot sin ayuda constante. | ☐ | ☐ | Niño 1 | ✘ | ✔ | ✔ | ✔ | Cumple
Comprendió las instrucciones del robot. | ☐ | ☐ | Niño 2 | ✔ | ✔ | ✔ | ✔ | Cumple
Interactuó de forma natural con el sistema. | ☐ | ☐ | Niño 3 | ✔ | ✔ | ✔ | ✔ | Cumple
Participó activamente durante toda la actividad. | ☐ | ☐ | Niño 4 | ✘ | ✔ | ✔ | ✔ | Cumple
 |  |  | Niño 5 | ✔ | ✔ | ✔ | ✔ | Cumple
Considera que el niño aprueba el indicador si cumple al menos 4 de los 5 criterios. |  |  | Niño 6 | ✘ | ✔ | ✔ | ✔ | Cumple
 |  |  | Niño 7 | ✔ | ✔ | ✔ | ✔ | Cumple
 |  |  | Niño 8 | ✘ | ✔ | ✔ | ✔ | Cumple
 |  |  | Niño 9 | ✔ | ✔ | ✔ | ✔ | Cumple
TABULACION DE DATOS |  |  | Niño 10 | ✘ | ✔ | ✔ | ✔ | Cumple
CUMPLE | 20 |  | Niño 11 | ✔ | ✔ | ✔ | ✔ | Cumple
NO CUMPLE | 0 |  | Niño 12 | ✔ | ✔ | ✔ | ✔ | Cumple
PORCENTAJE | 100% |  | Niño 13 | ✘ | ✔ | ✔ | ✔ | Cumple
 |  |  | Niño 14 | ✔ | ✔ | ✔ | ✔ | Cumple
 |  |  | Niño 15 | ✘ | ✔ | ✔ | ✔ | Cumple
 |  |  | Niño 16 | ✘ | ✔ | ✔ | ✔ | Cumple
 |  |  | Niño 17 | ✔ | ✔ | ✔ | ✔ | Cumple
 |  |  | Niño 18 | ✘ | ✔ | ✔ | ✔ | Cumple
 |  |  | Niño 19 | ✔ | ✔ | ✔ | ✔ | Cumple
 |  |  | Niño 20 | ✔ | ✘ | ✔ | ✔ | Cumple

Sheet: MATRIZ DE RESULTADOS ODS12
ODS 12 – Producción y Consumo Responsables
Indicador | Sí | No | Participante | C1 | C2 | C3 | C4 | CUMPLE ODS 12
Interactuo correctamente con el robot | ☐ | ☐ | Niño 1 | ✘ | ✔ | ✔ | ✔ | Cumple
Comprendio las instrucciones del robot | ☐ | ☐ | Niño 2 | ✔ | ✔ | ✔ | ✔ | Cumple
Colocó correctamente cada residuo en el contenedor correspondiente. | ☐ | ☐ | Niño 3 | ✔ | ✔ | ✔ | ✔ | Cumple
Participo activamente durante toda la actividad | ☐ | ☐ | Niño 4 | ✘ | ✔ | ✔ | ✔ | Cumple
 |  |  | Niño 5 | ✔ | ✔ | ✔ | ✔ | Cumple
Considera que el niño aprueba el indicador si cumple al menos 4 de los 5 criterios. |  |  | Niño 6 | ✔ | ✔ | ✔ | ✔ | Cumple
 |  |  | Niño 7 | ✘ | ✔ | ✔ | ✔ | Cumple
 |  |  | Niño 8 | ✔ | ✔ | ✔ | ✔ | Cumple
 |  |  | Niño 9 | ✔ | ✔ | ✔ | ✔ | Cumple
TABULACION DE DATOS |  |  | Niño 10 | ✘ | ✔ | ✔ | ✔ | Cumple
CUMPLE | 19 |  | Niño 11 | ✔ | ✔ | ✔ | ✔ | Cumple
NO CUMPLE | 1 |  | Niño 12 | ✘ | ✔ | ✔ | ✔ | Cumple
PORCENTAJE | 95% |  | Niño 13 | ✘ | ✘ | ✔ | ✔ | No cumple
 |  |  | Niño 14 | ✔ | ✔ | ✔ | ✔ | Cumple
 |  |  | Niño 15 | ✔ | ✔ | ✔ | ✔ | Cumple
 |  |  | Niño 16 | ✘ | ✔ | ✔ | ✔ | Cumple
 |  |  | Niño 17 | ✔ | ✔ | ✔ | ✘ | Cumple
 |  |  | Niño 18 | ✔ | ✔ | ✔ | ✘ | Cumple
 |  |  | Niño 19 | ✘ | ✔ | ✔ | ✔ | Cumple
 |  |  | Niño 20 | ✔ | ✘ | ✔ | ✔ | Cumple

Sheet: MATRIZ DE RESULTADOS ODS13
ODS 13 – Acción por el Clima
Indicador | Sí | No | Participante | C1 | C2 | C3 | CUMPLE ODS 13
Escuchó con atención la explicación del robot sobre el cuidado del ambiente. | ☐ | ☐ | Niño 1 | ✔ | ✔ | ✔ | Cumple
Participó activamente en la actividad ambiental. | ☐ | ☐ | Niño 2 | ✔ | ✔ | ✔ | Cumple
Mostró disposición para clasificar correctamente los residuos después de la explicación del robot. | ☐ | ☐ | Niño 3 | ✘ | ✔ | ✘ | No cumple
 |  |  | Niño 4 | ✔ | ✔ | ✔ | Cumple
Considera que el niño aprueba el indicador si cumple al menos 2 de los 3 criterios. |  |  | Niño 5 | ✔ | ✔ | ✔ | Cumple
 |  |  | Niño 6 | ✘ | ✔ | ✔ | Cumple
 |  |  | Niño 7 | ✔ | ✔ | ✔ | Cumple
 |  |  | Niño 8 | ✔ | ✔ | ✔ | Cumple
TABULACION DE DATOS |  |  | Niño 9 | ✔ | ✔ | ✔ | Cumple
CUMPLE | 19 |  | Niño 10 | ✘ | ✔ | ✔ | Cumple
NO CUMPLE | 1 |  | Niño 11 | ✔ | ✔ | ✔ | Cumple
PORCENTAJE | 95% |  | Niño 12 | ✔ | ✔ | ✔ | Cumple
 |  |  | Niño 13 | ✔ | ✔ | ✔ | Cumple
 |  |  | Niño 14 | ✘ | ✔ | ✔ | Cumple
 |  |  | Niño 15 | ✔ | ✔ | ✔ | Cumple
 |  |  | Niño 16 | ✔ | ✔ | ✔ | Cumple
 |  |  | Niño 17 | ✔ | ✔ | ✘ | Cumple
 |  |  | Niño 18 | ✔ | ✔ | ✔ | Cumple
 |  |  | Niño 19 | ✔ | ✔ | ✔ | Cumple
 |  |  | Niño 20 | ✔ | ✘ | ✔ | Cumple

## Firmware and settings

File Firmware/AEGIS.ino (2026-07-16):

#include <Arduino.h>
#include <Wire.h>
#include "src/globals.h"
#include "src/config.h"
#include "src/bluetooth.h"
#include "src/servos.h"
#include "src/locomotion.h"
#include "src/vision.h"
#include "src/audio.h"
#include "src/animations.h"
#include "src/battery.h"
#include "src/utils.h"

void setup() {
  Serial.begin(115200); 
  Wire.begin(); 
  
  // Inicialización modular jerárquica
  initAudio();
  initBluetooth();
  initServos();
  initVision();
  initBattery();
  
  standUp(); 
  Serial.println("✅ AEGIS EduBot: Inicialización modular exitosa.");
}

void loop() {
  // 1. LEER COMANDOS BLUETOOTH
  if (SerialBT.available()) {
    char dato = SerialBT.read();
    procesarBT(dato);
  }

  // 2. PROCESAR LA VISIÓN (CON TEMPORIZADOR ANTIBLOQUEO)
  static unsigned long tiempoUltimaMirada = 0;
  if (modoActual != '0' && huskyActivo == true && estado == 0) {
    // Frecuencia controlada a 150 ms para evitar latencia en Bluetooth
    if (millis() - tiempoUltimaMirada > 150) { 
      procesarVision();
      tiempoUltimaMirada = millis();
    }
  }

  // 3. MÁQUINA DE ESTADOS - EJECUTAR MARCHAS Y COMPORTAMIENTOS
  switch(estado) {
    case 1: trotStepRecto();     break;
    case 2: trotStepAtras();     break;
    case 3: trotStepIzquierda(); break;
    case 4: trotStepDerecha();   break;
    case 5: sentarseYDarMano();  break; 
  }

  // 4. TELEMETRÍA (Reporte cada 1 segundo)
  if (millis() - tiempoUltimoReporte > 1000) {
    imprimirSenales();
    tiempoUltimoReporte = millis();
  }
}

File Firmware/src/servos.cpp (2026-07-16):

#include "servos.h"
#include "globals.h"

void initServos() {
  pwm.begin();
  pwm.setPWMFreq(50);
}

void setServo(uint8_t canal, float angulo) {
  if (angulo < 0) angulo = 0;
  if (angulo > maxAngulos[canal]) angulo = maxAngulos[canal];
  currentAngles[canal] = angulo; 
  uint16_t pulso = SERVOMIN + (angulo / maxAngulos[canal]) * (SERVOMAX - SERVOMIN);
  pwm.setPWM(canal, 0, pulso);
}

void standUp() {
  setServo(B_FR, fr_B); setServo(F_FR, fr_F); setServo(T_FR, fr_T);
  setServo(B_FL, fl_B); setServo(F_FL, fl_F); setServo(T_FL, fl_T);
  setServo(B_RR, rr_B); setServo(F_RR, rr_F); setServo(T_RR, rr_T);
  setServo(B_RL, rl_B); setServo(F_RL, rl_F); setServo(T_RL, rl_T);
}

void moverGrupo(int targets[], int duracion) {
  unsigned long startTime = millis();
  float startAngles[12];
  for(int i=0; i<12; i++) startAngles[i] = currentAngles[i];

  while (millis() - startTime < (unsigned long)duracion) {
    float progreso = (float)(millis() - startTime) / duracion;
    float suave = (1.0 - cos(progreso * PI)) / 2.0; // Interpolación senoidal suave

    for (int i = 0; i < 12; i++) {
      if (targets[i] != -1) {
        float angIntermedio = startAngles[i] + (targets[i] - startAngles[i]) * suave;
        uint16_t pulso = SERVOMIN + (angIntermedio / maxAngulos[i]) * (SERVOMAX - SERVOMIN);
        pwm.setPWM(i, 0, pulso);
        currentAngles[i] = angIntermedio;
      }
    }
    if (SerialBT.available()) return; // Interrupción rápida por entrada de Bluetooth
  }
}

void setTargets(int t[], int val) { 
  for(int i = 0; i < 12; i++) t[i] = val; 
}

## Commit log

2026-07-15 Archivos BOM y README creados
    [BOM.xlsx]
2026-07-15 Archivo CAD agregado
    [Base cuerpo.stl, Cabeza perro.stl, Coxis frontal.stl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]
2026-07-16 Arreglo de algunas partes de la información, eliminación del archivo codigoCentral.txt, y archivos de resultados agregados
    [TABULACION DE DATOS.xlsx]

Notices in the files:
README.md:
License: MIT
